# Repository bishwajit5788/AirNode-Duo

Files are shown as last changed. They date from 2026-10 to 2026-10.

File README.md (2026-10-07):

# AirNode Duo

> **ESP32-C3 controlled dual-BLDC personal airflow and thermoelectric cooling system**

**Motto:** *Cool the person, not the room — compact airflow where it matters.*

Repository: [github.com/bishwajit5788/AirNode-Duo](https://github.com/bishwajit5788/AirNode-Duo)

---

## 1. Purpose

AirNode Duo is a compact personal airflow system meant to mount above a person inside:

- a mosquito net  
- a single-bed sleeping area  
- a lightweight camping tent  
- a compact temporary sleeping space  

Two BLDC motors with propellers produce **downward airflow** similar to a ceiling fan. The goal is **perceived cooling through forced convection** — moving useful air toward the person — not refrigerating a room.

**This system is not:**

- a room air conditioner  
- a refrigerator for the sleeping space  
- a device that produces ice-cold air  

Motor 1 may use an experimental thermoelectric liquid loop to slightly cool the air it moves. Motor 2 remains a normal, unobstructed airflow motor.

---

## 2. Physical architecture

```text
                  MOSQUITO NET / TENT ROOF
        ===========================================

              MOTOR 1             MOTOR 2
           2312 920KV CW       2312 920KV CW
                │                   │
              PROP 1              PROP 2
                ↓                   ↓
             cooled              normal
             airflow             airflow
                ↓                   ↓
              ↓↓↓↓↓             ↓↓↓↓↓
                 \               /
                  \             /
                   \           /
                    PERSON
```

- Two motors on a **lightweight, symmetric, roof-mounted frame**
- Heavy AC–DC PSU stays **outside** the hanging assembly
- Only low-voltage DC wiring runs up to the roof unit

---

## 3. Motors

| Item | Value |
|---|---|
| Part | Readytosky **2312 920KV CW** BLDC |
| Quantity | 2 |
| KV | ~920 RPM/V |
| Mass | ~48 g each |
| Diameter / body | ~27.7 mm OD × ~26 mm |
| No-load current | ~0.45 A at 10 V |
| Max continuous current | ~14 A (nameplate) |
| Max continuous power | ~220 W (nameplate) |
| Voltage class | ~2S–4S equivalent |
| Selected propeller | **9450 carbon fiber CW** (primary) |
| Other prop families considered | 9443, 9450, 1045 |

**Do not assume** “30 A ESC ⇒ 30 A motor current.” Actual current depends on propeller, voltage, throttle, blockage, and mounting. **Measure** current on the finished hardware.

---

## 4. Propellers

| Candidate | Role |
|---|---|
| **9450** | **Selected primary propeller** (carbon fiber, F450/F550 class) |
| 9443 | Lower-load baseline |
| 9350 | Smaller alternate |
| 1045 | Larger swept-area comparison |

**9450** is approximately **9.4″ diameter** (~**239 mm** tip-to-tip) with a **5.0″ pitch**.

Printed motor frames (motors **inside** the cages) are in [`hardware/frames/`](hardware/frames/):

- Motor 2 (air only): **253.47 × 253.47 × 61.0 mm** bottom + top grille  
- Motor 1 (copper coil under motor): **253.47 × 253.47 × 71.0 mm** bottom + top grille  

Always **measure** motor/ESC current and temperature with the installed 9450 + guards. Do not assume current from the ESC rating.

---

## 5. ESCs

| Item | Value |
|---|---|
| Part | Favorite **LittleBee 30A-S OPTO** × 2 |
| Class | 30 A, BLHeli_S, 2–6S |
| BEC | **None (OPTO)** |

- ESC #1 → Motor #1  
- ESC #2 → Motor #2  
- ESCs **do not** power the ESP32  
- ESP32 is powered by a separate **12 V → 5 V buck converter**

---

## 6. Main power supply

| Item | Value |
|---|---|
| PSU | 7SEVEN/MJF (or equivalent) |
| Rating | **12 V / 50 A / 600 W**, IP44 |

- PSU stays **outside** the hanging assembly  
- AC mains path: fuse → master switch → SMPS  

**Nameplate motor budget (upper bound, not measured load):**  
2 × 14 A = 28 A → 28 A × 12 V ≈ **336 W**.  
The 600 W PSU has headroom on paper; that is **not** validation of continuous 600 W system use. Other loads: Peltier, pump, hot-side fan, ESP32, losses. **Measure** real current and thermal behavior.

---

## 7. Electrical architecture

```text
                      230 V AC MAINS
                            │
                [Fuse + Master Switch]
                            │
                ┌───────────▼───────────┐
                │ 12 V / 50 A / 600 W   │
                │      AC-DC SMPS        │
                └───────────┬───────────┘
                            │
          ┌─────────┬───────┼───────┬─────────┐
          │         │       │       │         │
       ESC #1    ESC #2  Peltier  Pump   12→5 V buck
          │         │    driver   │         │
       Motor 1   Motor 2    TEC   │      ESP32-C3
          │         │             │      Wi-Fi AP
       PROP 1    PROP 2           │         │
                                  │       PHONE
                             (+ hot-side fan)
```

ESP32 GPIOs only drive **signal / driver** circuits. They must **not** power motors, ESCs, Peltier, or pump directly.

---

## 8. ESP32-C3 controller

**Board:** ESP32-C3 Mini (or compatible).

**Responsibilities:**

- Wi-Fi SoftAP + captive-portal helpers  
- Local web UI and HTTP API  
- Motor targets, ramp, START/STOP  
- Cooling sequence and interlocks  
- Heartbeat failsafe  
- Future sensor telemetry (not invented until sensors exist)

---

## 9. Wi-Fi user experience

1. Power on → ESP32 boots  
2. SoftAP appears: **AirNode-Duo**  
3. User joins the network  
4. Captive-portal detection *may* open the control page (OS-dependent)  
5. Always available: **http://192.168.4.1**  

**No internet required.** Core control is fully local.

| Setting | Value |
|---|---|
| SSID | `AirNode-Duo` |
| Password | `airnode123` |
| AP IP | `192.168.4.1` |
| Subnet | `255.255.255.0` |

Captive helpers include DNS wildcard → `192.168.4.1` and common paths such as `/generate_204`, `/hotspot-detect.html`, `/connecttest.txt`, `/ncsi.txt`, `/canonical.html`, `/success.txt`. **Do not claim** every phone OS will auto-open the page.

---

## 10. Phone control interface

Mobile-first local page:

- Title: **AirNode Duo**  
- Connection: ● CONNECTED / FAILSAFE / DISCONNECTED  
- IP: 192.168.4.1  
- System: ARMING / ARMED / RUNNING / STOPPED / FAILSAFE  
- Motor 1 & Motor 2: 2312 920KV CW, 0–100% sliders, target + applied %  
- Master speed: sets both targets (then adjustable independently)  
- **START** / **STOP** (STOP always prominent)  
- Thermoelectric cooling: ON/OFF, pump and TEC status  

---

## 11. Motor control behavior

| Phase | Behavior |
|---|---|
| Boot | Both ESC outputs **1000 µs**; motors stay off |
| Arm | Wait **3 s** before START is accepted |
| START | Explicit user action only; controlled **ramp** toward targets |
| STOP | Motors → off; cooling forced off |
| Failsafe | No valid control/heartbeat for **1.5 s** while running → motors + cooling off |

Browser sends heartbeats ~**500 ms**. After failsafe or reconnect, motors **do not** auto-restart; user must press **START** again.

Firmware ramps targets; it does **not** jump instantly from 0% to a high throttle on START.

---

## 12. Thermoelectric cooling (Motor 1)

**Concept:** Peltier cools **coolant**, not air directly. Coolant cools a copper coil; Motor 1 airflow passes over the coil.

```text
12 V Peltier → cold-side block → coolant → pump → tubing
    → copper coil (behind Motor 1 prop) → airflow → person
```

| Item | Notes |
|---|---|
| Peltier | ~12 V / ~2 A class (~20 W ideal); **not** room AC |
| Hot side | Aluminium heatsink + dedicated fan; heat must leave the cold path |
| Coil | Must **not** fully block the prop disc (load, current, heat rise) |
| Tube size | If “1 mm” is **internal** diameter, flow resistance may be excessive — verify ID vs wall |

### Cooling sequence (firmware)

1. COOLING ON  
2. Motor 1 running and applied ≥ ~**20%**  
3. Pump ON  
4. Wait ~**2 s** (prime)  
5. TEC driver ON → **ACTIVE**  

If Motor 1 stops / drops below threshold, or STOP/failsafe: **TEC off**, **pump off**.

### Cooling safety gaps (not yet instrumented)

Firmware does **not** yet verify coolant flow, hot-side temperature, cold-side temperature, or condensation. Future work: sensors, flow/pump-fail detection, condensation management. Avoid uncontrolled leakage above person, ESP32, ESCs, or power joints (sealed reservoir, secure fittings).

---

## 13. GPIO map (firmware defaults)

Centralized in `firmware/src/config.h` — do not scatter pin numbers.

| Function | GPIO | Notes |
|---|-----:|---|
| ESC #1 signal | 4 | Logic-level PWM only |
| ESC #2 signal | 5 | Logic-level PWM only |
| Pump driver | 6 | MOSFET/driver stage only |
| TEC driver | 7 | MOSFET/driver stage only |

Verify against the **exact** board pinout before connecting loads.

---

## 14. Firmware layout

```text
firmware/
├── platformio.ini
├── README.md          ← build, flash, API, bench checklist
└── src/
    ├── main.cpp
    ├── config.h
    ├── wifi_manager.*
    ├── web_server.*
    ├── motor_control.*
    ├── cooling_control.*
    └── web_ui.*
```

Responsibilities stay separated: Wi-Fi, web, motors, cooling, configuration, UI.

### HTTP API (local only)

| Method | Path | Role |
|---|---|---|
| GET | `/` | Control page |
| GET | `/api/status` | JSON state |
| POST | `/api/start` | Start (after arm) |
| POST | `/api/stop` | Hard stop |
| POST | `/api/control` | `m1`, `m2` ∈ 0…100 |
| POST | `/api/master` | `speed` ∈ 0…100 |
| POST | `/api/heartbeat` | Keep-alive |
| POST | `/api/cooling` | `on=0` or `on=1` |

All inputs validated and clamped. No fake temperature/current fields in JSON.

Example status:

```json
{
  "armed": true,
  "running": true,
  "failsafe": false,
  "motor1_target": 45,
  "motor1_applied": 42,
  "motor2_target": 45,
  "motor2_applied": 42,
  "cooling_requested": true,
  "pump": true,
  "tec": true,
  "clients": 1,
  "ip": "192.168.4.1"
}
```

Details: **[firmware/README.md](firmware/README.md)**.

---

## 15. Safety requirements

Rotating machinery above a person makes safety a **core** requirement.

**Mechanical:** full prop guards, rigid mounts, vibration-resistant fasteners, balanced frame, secondary tether, keep net fabric / hair / fingers out of the disc.

**Electrical:** AC fuse, master switch, proper mains enclosure/earthing as applicable, correct wire gauge, strain relief, secure connectors; AC section stays off the hanging assembly.

**Software:** motors off at boot; controlled ramp; heartbeat failsafe; no auto-restart after disconnect; cooling interlocks; reject invalid API input.

**Physical emergency disconnect** is strongly recommended. Software STOP is **not** the only emergency path.

---

## 16. Testing procedure

### Stage A — no propellers

**Remove both propellers** before any ESC test.

1. ESP32 boot, AP, phone join, `http://192.168.4.1`  
2. Captive-portal behavior where the OS supports it  
3. ESC arming (3 s), START at 0%, Motor 1 / Motor 2 independently  
4. STOP, Wi-Fi drop → failsafe within ~1.5 s, no auto-restart  
5. Cooling: pump before TEC; TEC off when Motor 1 low/stopped  

### Stage B — loaded (only after Stage A)

Propellers + guards; measure current, temperatures, vibration, noise, airflow; long-duration runs; cooling thermal and condensation checks.

**Firmware compile success ≠ hardware validation.**

---

## 17. Project status

**Stage:** Hardware architecture / **prototype development**

Repository includes concept docs, cooling diagrams, PlatformIO firmware (modular SoftAP UI, dual ESC, ramp, failsafe, cooling sequence), and CI build workflow.

| Claim type | Status |
|---|---|
| Firmware designed & modularized | Yes |
| Firmware compile verification | **Pending CI result after current PWM compatibility fix** |
| Physical motor/cooling validation | **Not complete** — pending bench & field tests |

Do **not** mark hardware validation complete without measurements.

---

## 18. Development roadmap

**Firmware (implemented in repo):**

- [x] ESP32-C3 Wi-Fi SoftAP (`AirNode-Duo` / `airnode123` → 192.168.4.1)  
- [x] Local web UI + captive-portal DNS/redirects  
- [x] Dual ESC PWM, independent + master speed  
- [x] Controlled startup ramp, explicit START/STOP  
- [x] Heartbeat failsafe (1.5 s; no auto-restart)  
- [x] Cooling sequence (pump prime → TEC; Motor 1 airflow interlock)  
- [x] Modular `src/` layout
- [x] Arduino-ESP32 3.x-compatible LEDC ESC output (14-bit at 50 Hz)
- [x] Arduino-ESP32 2.x compatibility path retained  

**Next / hardware:**

- [ ] Captive-portal polish on more phone OS versions  
- [ ] Current / voltage sensing  
- [ ] Motor, ESC, TEC hot-side, coolant temperature  
- [ ] Coolant flow / pump-fail detection  
- [ ] Live telemetry (only with real sensors)  
- [ ] Stronger cooling safety state machine  
- [ ] Physical emergency-stop input  
- [ ] Prop guards, frame, long-duration thermal/vibration tests  
- [x] Propeller selected: **9450 carbon fiber CW** (current/temp validation still required)  

---

## 19. Engineering rules (summary)

- Do not invent measurements or claim untested hardware capability  
- Do not treat 600 W PSU rating as actual system consumption  
- Do not equate PWM % with motor current  
- Do not claim the Peltier air-conditions the tent  
- Do not drive high-current loads from ESP32 GPIO  
- Do not auto-start motors after boot or after failsafe/reconnect  
- Do not enable TEC without pump-prime + airflow logic  
- Core control must work **without** internet or cloud  

---

## 20. Verification status

The repository is ready for the next software/bench-test stage, but physical operation is still unverified.

### Resolved in the current firmware

- Updated ESC PWM handling for Arduino-ESP32 3.x (ledcAttach / pin-based ledcWrite).
- Retained a compatibility path for Arduino-ESP32 2.x.
- Changed ESP32-C3 ESC PWM resolution from 16-bit to **14-bit**, matching the current Arduino-ESP32 LEDC range for ESP32-C3.
- Added a PWM-initialization failure lockout so the controller cannot arm motors if LEDC setup fails.

### Still requires physical hardware validation

- Exact ESP32-C3 board pinout.
- ESC signal/arming behavior with the selected LittleBee ESCs.
- Motor/propeller current and temperature.
- Propeller direction and downward airflow.
- Frame strength, vibration and guards.
- Peltier hot-side temperature.
- Coolant flow and leak resistance.
- Condensation behavior.
- Physical emergency disconnect.

**A successful firmware build does not prove that the motor/cooling system is safe for operation above a person.**

## 20. Documentation map

| Path | Role |
|---|---|
| **[README.md](README.md)** (this file) | Full project context, architecture, safety, roadmap |
| **[firmware/README.md](firmware/README.md)** | Build, flash, API, GPIO, bench checklist |
| [docs/project-concept.md](docs/project-concept.md) | Concept notes |
| [hardware/README.md](hardware/README.md) | Hardware notes |
| [docs/](docs/) / [hardware/](hardware/) | Diagrams and prototype media |

---

## 22. Intended end-to-end experience

```text
USER POWERS AIRNODE DUO
        │
        ▼
ESP32-C3 BOOTS  →  motors OFF, TEC OFF, pump OFF
        │
        ▼
Wi-Fi AP "AirNode-Duo"
        │
        ▼
PHONE CONNECTS  →  captive portal and/or http://192.168.4.1
        │
        ▼
CONTROL PAGE  →  motor + cooling UI
        │
        ├── START + sliders  →  ramped dual airflow
        └── COOLING ON       →  pump → TEC (if Motor 1 OK)
        │
        ▼
DOWNWARD AIRFLOW  →  PERSON

If phone lost → 1.5 s timeout → FAILSAFE (motors + cooling OFF)
                → wait for user START again
```

---

## License

Choose and declare a license that matches the firmware, CAD, and documentation you intend to publish.

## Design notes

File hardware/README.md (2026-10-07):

# AirNode Duo — Hardware

This directory is the central hardware documentation area for the AirNode Duo prototype.

## Purpose

AirNode Duo is a lightweight, roof-mounted, Wi-Fi-controlled dual-BLDC airflow system for a mosquito net / compact sleeping space.

The current prototype concept combines:

- **Motor 1:** 2312 920KV CW BLDC + 9450-class CW propeller (carbon fiber)
- **Motor 2:** 2312 920KV CW BLDC + 9450-class CW propeller (carbon fiber)
- **Motor 1 cooling stage:** 12 V / ~2 A Peltier + liquid coolant loop + copper tube coil behind the propeller
- **Motor 2:** normal unobstructed airflow
- **ESCs:** 2 × Favorite LittleBee 30A-S OPTO
- **Controller:** ESP32-C3
- **Main supply:** external 12 V / 50 A / 600 W AC-DC SMPS
- **Logic supply:** 12 V → 5 V buck converter
- **Cooling loop:** Peltier cold block → pump → flexible tube → copper coil → return
- **Hot side:** aluminium heatsink + dedicated cooling fan

## Hardware layout

The intended arrangement is:

```text
                         MOSQUITO-NET ROOF
────────────────────────────────────────────────────────

        MOTOR 1                                  MOTOR 2
      2312 920KV                               2312 920KV
           │                                        │
         9450                                     9450
           │                                        │
           ▼                                        ▼
   ┌───────────────┐                         NORMAL AIRFLOW
   │ COPPER COIL   │                               ↓↓↓
   │ HEAT EXCHANGER│                               ↓↓↓
   └───────┬───────┘                               ↓↓↓
           ↓
      COOLED AIRFLOW
           ↓
        OCCUPANT

        PELTIER
           │
      COLD-SIDE BLOCK
           │
        COOLANT
           │
          PUMP
           │
     PLASTIC TUBE
           │
     COPPER COIL
           │
         RETURN

    HOT SIDE → ALUMINIUM HEATSINK + FAN → HOT AIR AWAY
```

## Hardware specification

| Subsystem | Component | Specification / role |
|---|---|---|
| Airflow | 2 × BLDC motor | Readytosky 2312 920KV |
| Propeller | 2 × | 9450 carbon fiber CW; current/temp to be measured with guards |
| Motor ESC | 2 × | Favorite LittleBee 30A-S OPTO |
| Controller | 1 × | ESP32-C3, Wi-Fi web control |
| Main PSU | 1 × | 12 V / 50 A / 600 W external SMPS |
| Logic PSU | 1 × | 12 V → 5 V buck converter |
| TEC | 1 × | 12 V / ~2 A Peltier class |
| Cold-side exchanger | 1 × | Copper/aluminium water block |
| Liquid pump | 1 × | Small 12 V pump |
| Air heat exchanger | 1 × | Copper tube coil behind Motor 1 propeller |
| Tubing | As required | Flexible coolant tubing; size to be selected from pump/flow testing |
| Hot-side cooling | 1 × | Aluminium heatsink + 12 V cooling fan |
| Reservoir | 1 × | Sealed coolant reservoir |
| Sensors | Recommended | Hot-side, cold-side/coolant temperature; optional flow sensor |
| Safety | Required | Prop guards, fuse/protection, master disconnect, secondary safety tether |

## Photo archive

This folder is intentionally structured as a **living hardware archive**.

Add future prototype photographs here using descriptive filenames:

```text
hardware/
├── README.md
├── concept/
│   └── airnode-duo-minimal-diagram.jpg
├── prototype/
│   ├── 2026-XX-XX_frame.jpg
│   ├── 2026-XX-XX_motor-1.jpg
│   ├── 2026-XX-XX_motor-2.jpg
│   ├── 2026-XX-XX_peltier-loop.jpg
│   ├── 2026-XX-XX_copper-coil.jpg
│   ├── 2026-XX-XX_control-electronics.jpg
│   └── 2026-XX-XX_complete-prototype.jpg
└── testing/
    ├── airflow-test/
    ├── thermal-test/
    └── electrical-test/
```

### Photo naming convention

Use:

```text
YYYY-MM-DD_component_or_view_description.jpg
```

Examples:

- `2026-10-05_complete-prototype.jpg`
- `2026-10-05_motor-1-copper-coil.jpg`
- `2026-10-05_peltier-cold-block.jpg`
- `2026-10-05_hot-side-heatsink.jpg`
- `2026-10-05_esp32-esc-wiring.jpg`

For every real hardware photograph, add a short caption containing:

1. What is shown
2. Component/model
3. Purpose
4. Relevant specification
5. Prototype revision/date
6. Any important modification

## Important prototype notes

- The copper coil is a **liquid-to-air heat exchanger** positioned behind Motor 1's propeller.
- The Peltier must be thermally coupled to a proper cold-side block; do not rely on direct contact with the tube.
- The hot side must continuously reject heat through an adequately sized heatsink and fan.
- The coil must not excessively obstruct the propeller.
- If the proposed 1 mm copper tube means **1 mm internal diameter**, re-evaluate it because the pressure drop may be excessive for a small pump.
- Use a sealed reservoir and leak-resistant fittings because the assembly is positioned above the occupant.
- Condensation must be checked before continuous operation.
- Actual motor current must be measured with the final propeller before selecting operating limits.
- Software control is not the only safety mechanism: use physical electrical and mechanical protection.

## Current status

**Stage:** Concept / hardware preparation

**Next hardware milestone:** assemble and photograph the first physical frame, cooling loop and electrical/control assembly. Replace concept illustrations with real prototype photographs as the hardware becomes available.

## Current concept image

The current project concept image is stored directly in the hardware archive:

AirNode Duo hardware concept

This image represents the **current design concept**, not a photograph of the assembled physical prototype. Future real hardware photographs should be added under `hardware/prototype/` with dated filenames and captions.

## Concept diagrams

- [Thermoelectric cooling (SVG)](concept/airnode-duo-thermoelectric-cooling.svg) — schematic diagram
- [Thermoelectric cooling (PNG)](concept/airnode-duo-thermoelectric-cooling.png) — generated concept illustration
- [Thermoelectric cooling (JPG)](concept/airnode-duo-thermoelectric-cooling.jpg) — same illustration

## Propeller guards / motor frames (3D printed)

Printed parts live in **[`frames/`](frames/)** with a full parts list and print notes.

| Node | Bottom cage | Height Z | Notes |
|---|---|---|---|
| Motor 1 (cooled) | `frames/b-frame-71mm-cooled.stl` | **71.0 mm** | Extra height for copper coil under motor |
| Motor 2 (air only) | `frames/b-frame-61mm.stl` | **61.0 mm** | No liquid coil |
| Both | `frames/t-frame.stl`, `t-frame-2.stl` | **4.54 mm** | Top grilles (one per node) |

Outer footprint: **253.47 × 253.47 mm**. Motors mount **inside** the cages. Propeller: **9450** carbon (~239 mm disc).

See [`frames/README.md`](frames/README.md) for assembly, print settings, and fit notes.

## Center control / cooling enclosure

Low-profile box for ESP32-C3, **TEC1-12706**, 40×40 water block, heatsink+fan, and **RF-370CA-12560** pump.

| Part | File | Size (mm) |
|---|---|---|
| Body | [`enclosure/case-body.stl`](enclosure/case-body.stl) | **130 × 110 × 50** |
| Lid | [`enclosure/cap.stl`](enclosure/cap.stl) | **130 × 110 × 15** |

**Print-ready** open-top shell. Designed for **flat** TEC stack and **side** hot-air exhaust so height stays low on a mosquito net / tent.

Full notes: [`enclosure/README.md`](enclosure/README.md)

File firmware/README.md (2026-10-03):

# AirNode Duo — Firmware

PlatformIO firmware for the ESP32-C3 SoftAP controller.

For full project architecture, safety, and hardware context, see the **[root README](../README.md)**.

---

## Quick start

```bash
cd firmware
pio run                 # build
pio run -t upload       # flash
pio device monitor      # 115200 baud
```

---

## Wi-Fi

| Setting | Value |
|---|---|
| SSID | `AirNode-Duo` |
| Password | `airnode123` |
| Control URL | **http://192.168.4.1** |

No internet required. Captive-portal DNS/redirects are implemented; phone OS behavior varies — use the URL if the page does not open automatically.

---

## GPIO defaults (`src/config.h`)

| Function | GPIO |
|---|-----:|
| ESC #1 | 4 |
| ESC #2 | 5 |
| Pump driver | 6 |
| TEC driver | 7 |

Verify against your board. Drivers only — never load GPIO directly with pump/Peltier/motor power.

---

## PWM compatibility

The ESC outputs use **50 Hz servo-style PWM** with **14-bit LEDC resolution** on ESP32-C3.

The implementation supports the current Arduino-ESP32 3.x LEDC API (`ledcAttach` / pin-based `ledcWrite`) and retains a compatibility path for Arduino-ESP32 2.x.

If LEDC initialization fails, the firmware locks the motor outputs off and does not arm the controller.

## API

| Method | Path | Body / notes |
|---|---|---|
| GET | `/` | Control UI |
| GET | `/api/status` | JSON |
| POST | `/api/start` | After 3 s arm |
| POST | `/api/stop` | Motors + cooling off |
| POST | `/api/control` | `m1=0..100&m2=0..100` |
| POST | `/api/master` | `speed=0..100` |
| POST | `/api/heartbeat` | ~500 ms from browser |
| POST | `/api/cooling` | `cooling=0..100` or `on=0|1` (also JSON) |

Failsafe: no valid control for **1.5 s** while running → stop motors and cooling; no auto-restart.

---

## Source layout

```text
src/
  main.cpp
  config.h
  wifi_manager.*
  web_server.*
  motor_control.*
  cooling_control.*
  web_ui.*
```

---

## Bench test (propellers **removed**)

1. Power ESP32 from 12 V → 5 V buck; ESCs from 12 V per manufacturer wiring.  
2. Flash, join **AirNode-Duo**, open **http://192.168.4.1**.  
3. Wait until UI shows **ARMED**.  
4. START at 0%; raise Motor 1 then Motor 2 slowly.  
5. Drop Wi-Fi / close page → failsafe within ~1.5 s.  
6. Reconnect → motors stay off until **START**.  
7. Cooling: Motor 1 ≥ 20% → COOLING ON → pump then TEC after ~2 s.  

Software failsafe is not a substitute for a physical emergency disconnect.

**Build status:** use the GitHub Actions workflow as the authoritative compile check; this document does not claim a successful build until CI reports one.

Only after this passes should propellers and loaded tests begin (see root README).

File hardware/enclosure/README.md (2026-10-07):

# AirNode Duo — Center control / cooling enclosure

Low-profile 3D-printed box for the **balanced center node** on the mosquito-net / tent structure.

## Files (print-ready)

| File | Role | Bounding box (mm) | Mesh notes |
|---|---|---|---|
| `case-body.stl` | Main body | **130 × 110 × 50** | **Open top** for lid; cleaned for FDM |
| `cap.stl` | Lid | **130 × 110 × 15** | Watertight; print flat |

## 3D print settings (recommended)

| Setting | Body | Lid |
|---|---|-----|
| Material | **PETG** | PETG |
| Nozzle | 0.4 mm | 0.4 mm |
| Layer height | **0.20 mm** | 0.20 mm |
| Walls / perimeters | **3** | 3 |
| Top/bottom layers | 4–5 | 4–5 |
| Infill | **15–25%** gyroid or grid | 15–25% |
| Supports | **None** (correct orientation) | None |
| Orientation | **Open face UP**, floor on bed | Flat on bed |

### Orientation

```text
case-body.stl                 cap.stl
   open top ↑
   ┌─────────┐               ┌─────────┐
   │  cavity │               │   lid   │
   │  floor  │ ← on bed      └─────────┘ ← on bed
   └─────────┘
```

### Printability

- Body is an **open-top shell** (not a sealed hollow bubble) so FDM slices cleanly.
- Floor at Z = 0 for bed contact.
- After print: drill **Ø8–9 mm** side holes for RF-370 / block tubing if needed.
- Cut or design a **side grille** for TEC heatsink fan exhaust (hot air out, not into the net).

### Fit

| Item | Guidance |
|---|---|
| Internal height | ~47–48 mm above floor |
| Pump RF-370 | ~84 mm × Ø29 — along 130 mm axis |
| TEC stack | **Flat**; fan exhaust **sideways** |
| Lid | Light friction or M3 corner screws |

## Contents

| Component | Spec |
|---|---|
| ESP32-C3 + buck 12→5 V | Dry side |
| TEC1-12706 | 40×40×~3.8 mm; MOSFET only (~4–6 A) |
| Water block | 40×40×(12+7) mm |
| Heatsink + fan | Compact TEC kit |
| Pump | RF-370CA-12560, Ø8 mm ports |

## Safety

- TEC/pump via MOSFET — never direct ESP32 GPIO.
- Leak-test before enabling TEC.
- Secondary tether on hanging assembly.

## Related

- Motor frames: [`../frames/`](../frames/)
- Hardware overview: [`../README.md`](../README.md)

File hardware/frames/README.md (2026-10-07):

# AirNode Duo — 3D-printed motor frames

Printed propeller guards / motor cages for the dual-node AirNode Duo prototype.

Motors mount **inside** the frames. Each node is a **bottom cage + top grille**.

## Files

| File | Role | Bounding box (mm) | Triangles |
|---|---|---|---|
| `b-frame-61mm.stl` | **Motor 2** bottom cage (air-only, no liquid coil) | **253.47 × 253.47 × 61.0** | 240 288 |
| `b-frame-71mm-cooled.stl` | **Motor 1** bottom cage (space for copper cooling coil under motor) | **253.47 × 253.47 × 71.0** | 240 288 |
| `t-frame.stl` | Top grille (pair with either bottom) | **253.47 × 253.47 × 4.54** | 102 108 |
| `t-frame-2.stl` | Second top grille (print one per node) | **253.47 × 253.47 × 4.54** | 102 108 |

## Which frame for which motor

```text
Motor 1 (cooled path)          Motor 2 (normal airflow)
┌─────────────────────┐        ┌─────────────────────┐
│ t-frame*.stl        │        │ t-frame*.stl        │
│ 9450 prop           │        │ 9450 prop           │
│ 2312 motor          │        │ 2312 motor          │
│ copper coil ~20 mm  │        │ (no coil)           │
│ b-frame-71mm-cooled │        │ b-frame-61mm        │
└─────────────────────┘        └─────────────────────┘
     Z = 71 mm                      Z = 61 mm
     X = Y ≈ 253.5 mm               X = Y ≈ 253.5 mm
```

| Node | Bottom STL | Top STL | Z height |
|---|---|---|---|
| **Motor 1** (Peltier liquid coil under motor) | `b-frame-71mm-cooled.stl` | `t-frame.stl` or `t-frame-2.stl` | **71.0 mm** |
| **Motor 2** (no coil) | `b-frame-61mm.stl` | `t-frame.stl` or `t-frame-2.stl` | **61.0 mm** |

Height difference (**+10 mm** on Motor 1) is for the self-made thin copper cooling coil (~15–20 mm pack) under the motor inside the cage.

## Propeller compatibility

| Item | Value |
|---|---|
| Propeller | **9450** carbon fiber (F450/F550 class), CW |
| Prop disc | ~**9.4″ ≈ 239 mm** tip-to-tip |
| Frame outer | ~**253.5 mm** |
| Typical wall | ~3–4 mm → inner clear ~**245–247 mm** |
| Fit | **Usable** if prop is centered; measure real prop and inner Ø before high throttle |

## Motor compatibility

| Item | Value |
|---|---|
| Motor | Readytosky **2312 920KV** CW |
| Body height | **26.0 mm** (datasheet) |
| Body diameter | **27.7 mm** |
| Mount | **12 × 16 mm** M3 pattern — verify against base plate holes |

## Bill of printed parts (one complete dual-motor set)

- 1 × `b-frame-71mm-cooled.stl` (Motor 1)
- 1 × `b-frame-61mm.stl` (Motor 2)
- 2 × top grille (`t-frame.stl` + `t-frame-2.stl`)

## Suggested print settings (Bambu Lab A1 reference)

| Setting | Suggestion |
|---|---|
| Material | **PETG** (toughness for guards) |
| Nozzle | 0.4 mm |
| Layer height | 0.20 mm |
| Walls | 3 loops |
| Infill | 15–25% (tri-hexagon or gyroid) |
| Supports | As needed for the side windows / overhangs |
| Orientation | Base flat on bed (Z up) |

Always dry-fit **motor + prop (and coil on Motor 1)** before final assembly.

## Assembly notes

1. Mount the **2312** to the center of the **bottom** cage (motor inside).
2. Install **9450** on the motor shaft (correct CW direction for downward airflow).
3. On Motor 1 only: place the **copper coil** under the motor / in the extra Z space; route inlet/outlet through a side opening — do not fully block the prop disc.
4. Fit the **top grille**; ensure prop tips clear the inner wall and grille.
5. Route ESC/signal wires out a side window with strain relief.
6. Use a **secondary safety tether** on the hanging assembly.

## Safety

- First electrical tests: **propellers removed**.
- First spinning tests: low throttle, guards on, no body over the disc.
- These frames are **guards**, not a substitute for careful mounting and current measurement.

## Source

Derived from a freely available fan-cover / 风扇罩 style model, scaled in Z per node:

- Motor 2 air-only: **Z = 61 mm**
- Motor 1 cooled: **Z = 71 mm**
- X/Y held at model outer ~**253.5 mm**

Original concept dimensions and AirNode Duo system docs: see [`../README.md`](../README.md) and the repository root `README.md`.

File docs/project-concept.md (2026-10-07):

# AirNode Duo — Project Concept

## Motto

> **Cool the person, not the room — compact airflow where it matters.**

## Physical arrangement

AirNode Duo uses two roof-mounted BLDC rotors positioned over the sleeping area. Both rotors are intended to produce **downward airflow**, creating a ceiling-fan-like circulation pattern.

The heavy AC-to-DC SMPS remains on the floor/table or another protected location. The roof assembly carries only the lightweight motors, ESCs, ESP32-C3, buck converter, wiring and safety hardware.

```text
                 ROOF OF MOSQUITO NET / TENT
        ──────────────────────────────────────────

              ┌───────────┐     ┌───────────┐
              │ 2312 920KV│     │ 2312 920KV│
              │  BLDC #1  │     │  BLDC #2  │
              └─────┬─────┘     └─────┬─────┘
                    │                   │
                ┌───▼───┐           ┌───▼───┐
                │  PROP  │           │  PROP  │
                └───┬───┘           └───┬───┘
                    ↓↓↓                 ↓↓↓
                 ↓↓↓↓↓↓↓             ↓↓↓↓↓↓↓
                    ↓↓↓                 ↓↓↓
                                      /
                                     /
                                    /
                          ▼▼▼▼▼▼▼▼▼
                         PERSON / BED

        ══════════════════════════════════════════
               12 V DC CABLE FROM OUTSIDE
                          │
                   ┌──────▼──────┐
                   │ 12V/50A/600W│
                   │     SMPS    │
                   └─────────────┘
                         230 V AC
```

## Motor 1 thermoelectric cooling module

The current concept adds a **12 V / ~2 A Peltier cooling stage to Motor 1**.

The Peltier does not sit directly in the propeller airflow. Instead:

1. The Peltier cold side cools a liquid through a proper cold-side thermal block.
2. A small pump circulates the coolant through flexible plastic tubing.
3. The coolant passes through a **copper tube coil positioned behind Motor 1's propeller**.
4. Motor 1 forces air across the copper coil.
5. The resulting cooled airflow continues downward toward the occupant.
6. The Peltier hot side is cooled separately with an aluminium heatsink and fan, with hot air directed away from the occupant.

```text
             MOTOR 1
          2312 920KV
               │
             9350
               ↓↓↓
        ┌───────────────┐
        │ COPPER COIL   │  ← coolant from pump
        └───────┬───────┘
                ↓↓↓
          COOLED AIRFLOW
                ↓↓↓
             PERSON

     PELTIER → COLD BLOCK → PUMP → COIL
        │
        └→ HOT SIDE → ALUMINIUM HEATSINK + FAN → HOT AIR OUT
```

The copper coil is therefore a **liquid-to-air heat exchanger**. It should not cover the entire propeller disc because excessive airflow blockage can reduce airflow and increase motor load.

A proper cold-side plate/water block and thermal interface material are required between the Peltier and coolant. If the proposed "1 mm copper tube" refers to internal diameter, a larger coolant passage should be considered because a very small passage can create excessive pressure drop.

Because the cold coil may reach temperatures below ambient dew point, condensation must be considered. A sealed coolant reservoir, leak-resistant fittings and temperature monitoring are recommended before mounting the system above a person.

## Design intent

The purpose is not to cool the whole room. The system creates a controlled local airflow stream across the occupant, which can improve perceived thermal comfort through increased convective heat transfer and evaporation.

The final system should prioritize:
- low mass on the net/tent roof;
- balanced and vibration-resistant mounting;
- controlled continuous airflow;
- independent rotor control;
- reliable shutdown on communication loss;
- physical rotor and electrical protection.

## Important design note

The two motors are both CW variants. Rotor direction and propeller installation must be verified experimentally so **both rotors produce the intended downward airflow**. Motor label convention alone does not establish airflow direction.

The hardware documentation is now maintained in `hardware/README.md`, with `hardware/concept/` reserved for clean concept diagrams and `hardware/prototype/` reserved for dated real-hardware photographs. Future prototype photos should document the frame, motors, propellers, copper coil, Peltier assembly, pump, wiring, controller and complete system.

## Current integrated hardware concept

The project has now evolved from a dual-airflow prototype into a **dual-airflow + Motor 1 thermoelectric cooling prototype**.

### Motor 1 — cooled airflow

**2312 920KV CW motor → 9350-class propeller → copper coolant coil → cooled downward airflow → occupant.**

The copper coil is a liquid-to-air heat exchanger. Coolant is circulated by a small pump through flexible tubing. The Peltier cools the coolant through a proper cold-side copper/aluminium block.

### Motor 2 — normal airflow

**2312 920KV CW motor → 9350-class propeller → unobstructed downward airflow → occupant.**

This provides independent airflow even when the thermoelectric stage is disabled.

### Thermal rejection

The Peltier hot side uses a dedicated aluminium heatsink and cooling fan. Hot air must be exhausted away from the occupant and away from the cooled coil. The Peltier's electrical input becomes additional heat that the hot side must reject, so heatsink capacity is a critical part of the design.

### Safety and validation priorities

- Use full propeller guards and a secondary safety tether.
- Keep the 230 V AC SMPS outside the hanging assembly.
- Use a sealed coolant reservoir and leak-resistant fittings.
- Add hot-side and cold-side/coolant temperature monitoring.
- Disable the Peltier if the hot side becomes too hot or coolant flow fails.
- Check for condensation before operation above a person.
- Do not allow the copper coil to excessively obstruct the propeller.
- Measure actual motor current with the final propeller before defining continuous operating limits.

### Hardware documentation structure

The repository now uses `hardware/README.md` as the central hardware file. It is intended to grow with the project and will contain future dated photographs and test documentation as the physical hardware arrives.

Current concept illustration:
`hardware/concept/airnode-duo-thermoelectric-cooling.svg`

Future real photographs:
`hardware/prototype/YYYY-MM-DD_description.jpg`

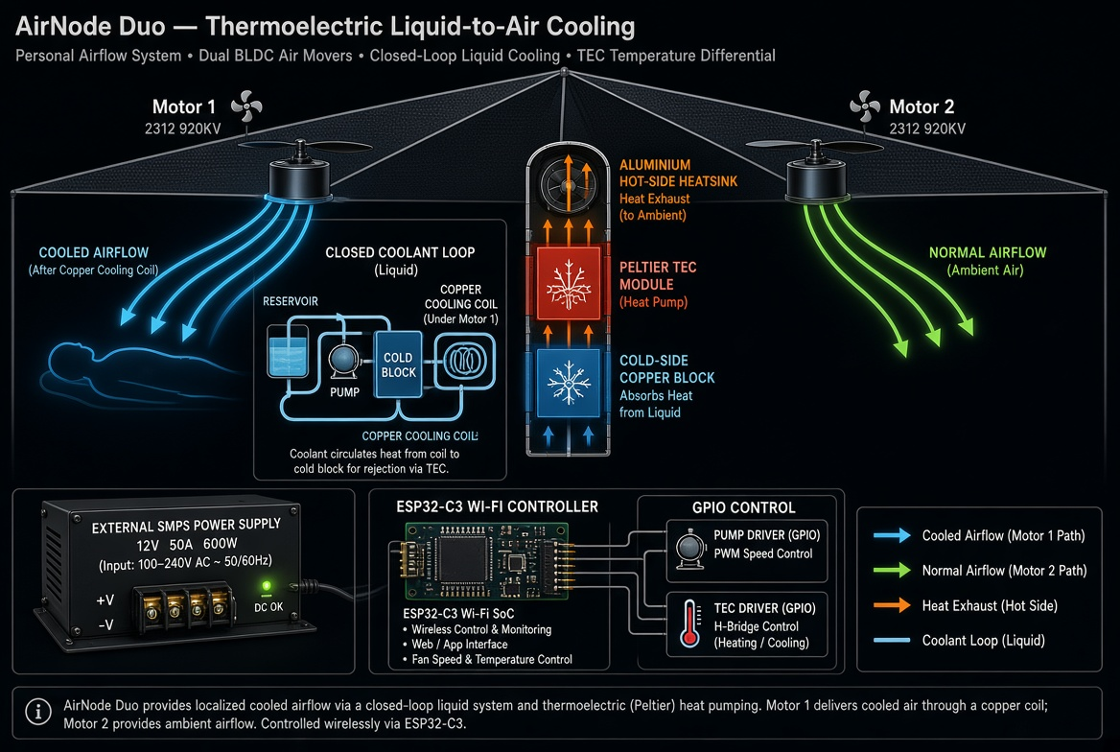
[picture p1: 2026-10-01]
hardware/concept/airnode-duo-thermoelectric-cooling.png

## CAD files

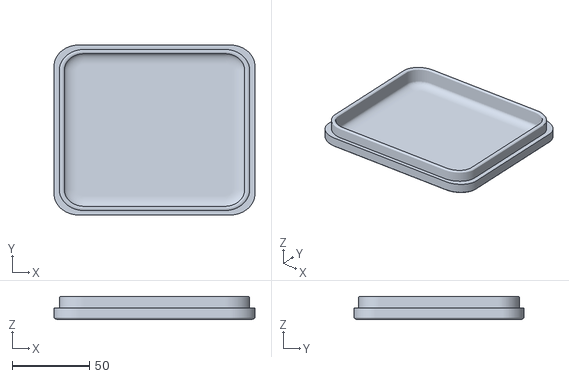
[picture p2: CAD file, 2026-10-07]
hardware/enclosure/cap.stl
130.0 x 110.0 x 15.0

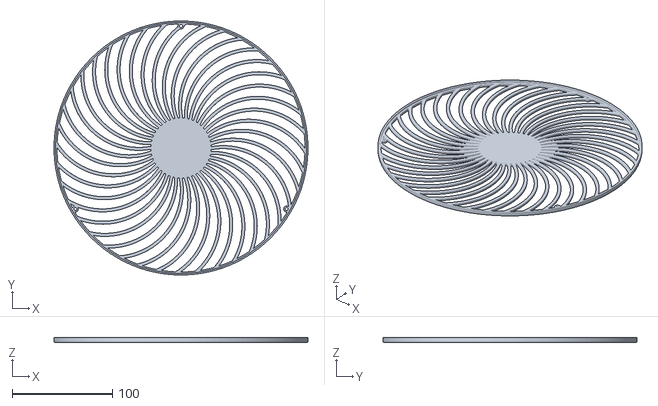
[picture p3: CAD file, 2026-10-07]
hardware/frames/t-frame.stl
253.5 x 253.5 x 4.54

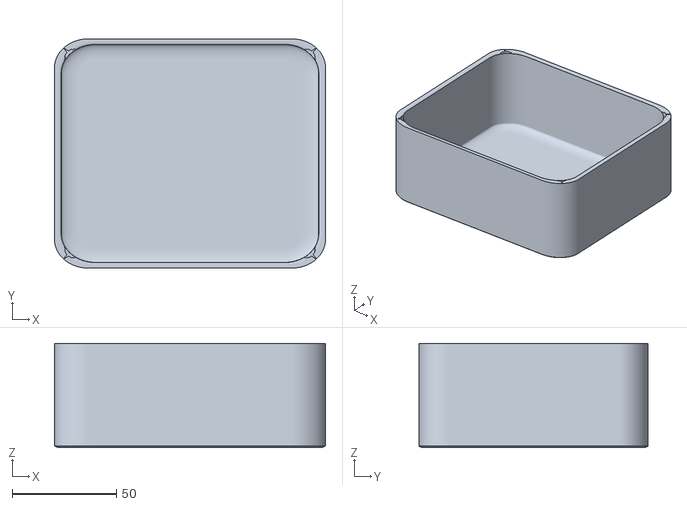
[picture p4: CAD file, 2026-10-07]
hardware/enclosure/case-body.stl
130.0 x 110.0 x 50.0

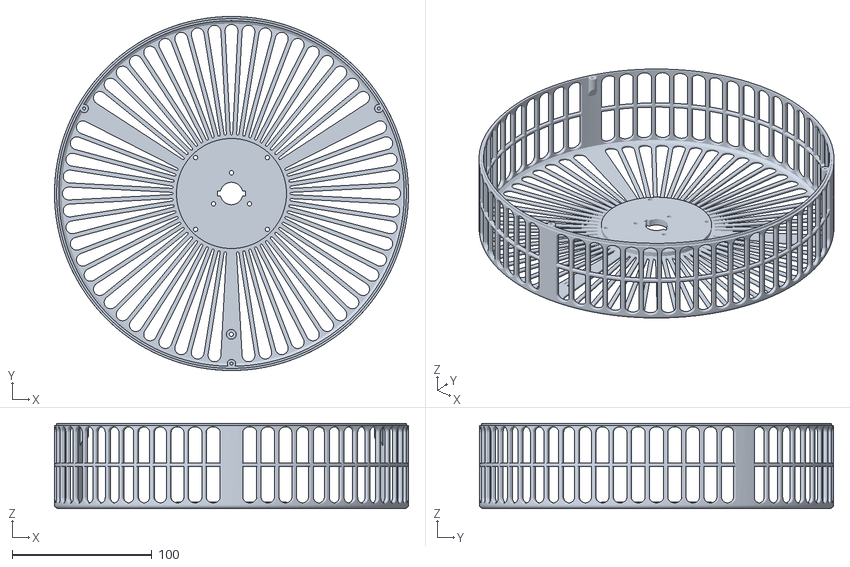
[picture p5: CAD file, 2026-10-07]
hardware/frames/b-frame-61mm.stl
253.5 x 253.5 x 61.0

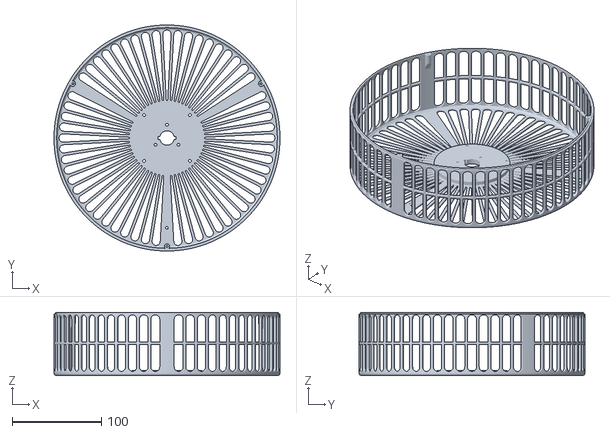
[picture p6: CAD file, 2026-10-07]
hardware/frames/b-frame-71mm-cooled.stl
253.5 x 253.5 x 71.0

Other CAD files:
hardware/frames/t-frame-2.stl

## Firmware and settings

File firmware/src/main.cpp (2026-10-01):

#include <Arduino.h>
#include "config.h"
#include "motor_control.h"
#include "cooling_control.h"
#include "wifi_manager.h"
#include "web_server.h"

void setup() {
  Serial.begin(115200);
  delay(50);

  Serial.println();
  Serial.println("AirNode Duo firmware booting...");

  MotorControl::begin();
  CoolingControl::begin();
  WifiManager::begin();
  WebServerApp::begin();

  Serial.println("Ready. Open http://192.168.4.1 after joining AirNode-Duo.");
}

void loop() {
  WifiManager::process();
  WebServerApp::process();

  MotorControl::update();

  // Cooling supervision uses live motor state
  CoolingControl::update(MotorControl::isRunning(), MotorControl::motor1Applied());

  // If failsafe just triggered motors, ensure cooling is off
  if (MotorControl::isFailsafe() && CoolingControl::isRequested()) {
    CoolingControl::forceOff();
  }

  delay(2);
}

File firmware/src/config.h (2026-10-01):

#pragma once

// AirNode Duo ESP32-C3 firmware configuration.
// Verify every GPIO against your exact ESP32-C3 board before connecting an ESC,
// pump driver, or TEC driver. Do not connect a load directly to an ESP32 GPIO.

// ---------------------------------------------------------------------------
// Wi-Fi SoftAP
// ---------------------------------------------------------------------------
#define AIRNODE_AP_SSID       "AirNode-Duo"
#define AIRNODE_AP_PASSWORD   "airnode123"
#define AIRNODE_AP_CHANNEL    6
#define AIRNODE_AP_MAX_CLIENTS 4

#define AIRNODE_IP_1 192
#define AIRNODE_IP_2 168
#define AIRNODE_IP_3 4
#define AIRNODE_IP_4 1

// ---------------------------------------------------------------------------
// GPIO map (centralized — do not hard-code pins elsewhere)
// ---------------------------------------------------------------------------
// ESC signal outputs. Logic-level PWM only (50 Hz servo-style).
// ESP32-C3 LEDC supports up to 14-bit resolution in Arduino-ESP32 3.x.
#define ESC1_PIN 4
#define ESC2_PIN 5

// Driver-control outputs. Must drive MOSFET/driver stages, never the load.
// Set to -1 when the hardware is not fitted.
#define PUMP_PIN 6
#define TEC_PIN  7

// ---------------------------------------------------------------------------
// ESC PWM
// ---------------------------------------------------------------------------
#define ESC_PWM_HZ          50
#define ESC_PWM_RESOLUTION  16
#define ESC_MIN_US          1000
#define ESC_MAX_US          2000

// ---------------------------------------------------------------------------
// Timing / safety
// ---------------------------------------------------------------------------
#define ESC_ARM_TIME_MS         3000   // hold min pulse before accepting START
#define CONTROL_TIMEOUT_MS      1500   // failsafe if no heartbeat
#define HEARTBEAT_EXPECTED_MS    500   // browser target interval
#define START_RAMP_PCT_PER_S      35   // controlled ramp rate
#define COOLANT_PRIME_MS        2000   // pump run time before TEC enable
#define COOLING_MIN_MOTOR1_PCT    20   // min Motor 1 applied % for TEC

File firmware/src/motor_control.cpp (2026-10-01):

#include "motor_control.h"

namespace MotorControl {

// Stable logical channel IDs are retained for Arduino-ESP32 2.x compatibility.
// Arduino-ESP32 3.x assigns the physical LEDC channel automatically.
static const uint8_t CH_ESC1 = 0;
static const uint8_t CH_ESC2 = 1;

static uint8_t s_m1Target = 0;
static uint8_t s_m2Target = 0;
static uint8_t s_m1Applied = 0;
static uint8_t s_m2Applied = 0;
static bool s_armed = false;
static bool s_running = false;
static bool s_failsafe = false;
static bool s_pwmReady = false;
static uint32_t s_bootMs = 0;
static uint32_t s_lastControlMs = 0;
static uint32_t s_lastRampMs = 0;

static uint32_t pulseToDuty(uint16_t us) {
  // 50 Hz => 20,000 us period. Use the configured LEDC resolution.
  const uint32_t dutyMax = (1UL << ESC_PWM_RESOLUTION) - 1UL;
  return ((uint32_t)us * dutyMax) / 20000UL;
}

static void writeEscPulse(uint8_t pin, uint8_t channel, uint16_t us) {
  us = constrain(us, (uint16_t)ESC_MIN_US, (uint16_t)ESC_MAX_US);
  const uint32_t duty = pulseToDuty(us);

#if defined(ESP_ARDUINO_VERSION_MAJOR) && (ESP_ARDUINO_VERSION_MAJOR >= 3)
  // Arduino-ESP32 3.x LEDC writes are pin-based.
  (void)channel;
  ledcWrite(pin, duty);
#else
  // Arduino-ESP32 2.x LEDC writes are channel-based.
  (void)pin;
  ledcWrite(channel, duty);
#endif
}

static uint16_t percentToPulse(uint8_t pct) {
  pct = constrain(pct, (uint8_t)0, (uint8_t)100);
  return ESC_MIN_US + ((uint32_t)pct * (ESC_MAX_US - ESC_MIN_US)) / 100UL;
}

static void applyOutputs() {
  if (!s_pwmReady) return;
  writeEscPulse(ESC1_PIN, CH_ESC1, percentToPulse(s_m1Applied));
  writeEscPulse(ESC2_PIN, CH_ESC2, percentToPulse(s_m2Applied));
}



void begin() {
  s_bootMs = millis();
  s_lastRampMs = s_bootMs;
  s_lastControlMs = s_bootMs;
  s_armed = false;
  s_running = false;
  s_failsafe = false;
  s_pwmReady = false;
  s_m1Target = s_m2Target = 0;
  s_m1Applied = s_m2Applied = 0;

#if defined(ESP_ARDUINO_VERSION_MAJOR) && (ESP_ARDUINO_VERSION_MAJOR >= 3)
  const bool esc1Ok = ledcAttach(ESC1_PIN, ESC_PWM_HZ, ESC_PWM_RESOLUTION);
  const bool esc2Ok = ledcAttach(ESC2_PIN, ESC_PWM_HZ, ESC_PWM_RESOLUTION);
  s_pwmReady = esc1Ok && esc2Ok;
#else
  ledcSetup(CH_ESC1, ESC_PWM_HZ, ESC_PWM_RESOLUTION);
  ledcSetup(CH_ESC2, ESC_PWM_HZ, ESC_PWM_RESOLUTION);
  ledcAttachPin(ESC1_PIN, CH_ESC1);
  ledcAttachPin(ESC2_PIN, CH_ESC2);
  s_pwmReady = true;
#endif

  if (!s_pwmReady) {
    Serial.println("ERROR: ESC PWM initialization failed; motors locked off.");
    return;
  }

  writeEscPulse(ESC1_PIN, CH_ESC1, ESC_MIN_US);
  writeEscPulse(ESC2_PIN, CH_ESC2, ESC_MIN_US);
  Serial.printf("ESC PWM ready: %u Hz, %u-bit, outputs held at %u us.\n",
                ESC_PWM_HZ, ESC_PWM_RESOLUTION, ESC_MIN_US);
}

void update() {
  if (!s_pwmReady) return;

  if (!s_armed && (millis() - s_bootMs) >= ESC_ARM_TIME_MS) {
    s_armed = true;
    Serial.println("ESC arming complete.");
  }

  if (s_running && !hasRecentControl()) {
    Serial.println("FAILSAFE: control heartbeat timeout");
    triggerFailsafe();
  }

  if (!s_armed || !s_running) {
    if (s_m1Applied || s_m2Applied) {
      s_m1Applied = s_m2Applied = 0;
      applyOutputs();
    }
    return;
  }

  const uint32_t now = millis();
  const uint32_t dt = now - s_lastRampMs;
  if (!dt) return;
  s_lastRampMs = now;

  const uint8_t step = max<uint8_t>(1, (uint8_t)((START_RAMP_PCT_PER_S * dt) / 1000UL));

  if (s_m1Applied < s_m1Target)
    s_m1Applied = min<uint8_t>(s_m1Target, (uint8_t)(s_m1Applied + step));
  else if (s_m1Applied > s_m1Target)
    s_m1Applied = (s_m1Applied > step) ? (uint8_t)(s_m1Applied - step) : 0;

  if (s_m2Applied < s_m2Target)
    s_m2Applied = min<uint8_t>(s_m2Target, (uint8_t)(s_m2Applied + step));
  else if (s_m2Applied > s_m2Target)
    s_m2Applied = (s_m2Applied > step) ? (uint8_t)(s_m2Applied - step) : 0;

  applyOutputs();
}

bool isArmed() { return s_armed && s_pwmReady; }
bool isRunning() { return s_running; }
bool isFailsafe() { return s_failsafe; }

uint8_t motor1Target() { return s_m1Target; }
uint8_t motor2Target() { return s_m2Target; }
uint8_t motor1Applied() { return s_m1Applied; }
uint8_t motor2Applied() { return s_m2Applied; }

void setTargets(uint8_t m1, uint8_t m2) {
  s_m1Target = constrain(m1, (uint8_t)0, (uint8_t)100);
  s_m2Target = constrain(m2, (uint8_t)0, (uint8_t)100);
  touchControl();
}

void start() {
  if (!isArmed()) return;
  s_failsafe = false;
  s_running = true;
  s_lastRampMs = millis();
  touchControl();
}

void stop() {
  s_running = false;
  s_m1Target = s_m2Target = 0;
  s_m1Applied = s_m2Applied = 0;
  applyOutputs();
  touchControl();
}

void triggerFailsafe() {
  s_failsafe = true;
  s_running = false;
  s_m1Target = s_m2Target = 0;
  s_m1Applied = s_m2Applied = 0;
  applyOutputs();
}

void touchControl() {
  s_lastControlMs = millis();
}

bool hasRecentControl() {
  return (millis() - s_lastControlMs) <= CONTROL_TIMEOUT_MS;
}

}  // namespace MotorControl

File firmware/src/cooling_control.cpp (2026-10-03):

#include "cooling_control.h"

namespace CoolingControl {

static uint8_t s_level = 0;
static bool s_pumpOn = false;
static bool s_tecOn = false;
static uint32_t s_primeStartMs = 0;

void begin() {
  s_level = 0;
  s_pumpOn = false;
  s_tecOn = false;
  s_primeStartMs = 0;

#if PUMP_PIN >= 0
  pinMode(PUMP_PIN, OUTPUT);
  digitalWrite(PUMP_PIN, LOW);
#endif
#if TEC_PIN >= 0
  pinMode(TEC_PIN, OUTPUT);
  digitalWrite(TEC_PIN, LOW);
#endif
}

static void setPump(bool on) {
#if PUMP_PIN >= 0
  digitalWrite(PUMP_PIN, on ? HIGH : LOW);
#endif
  s_pumpOn = on;
}

static void setTec(bool on) {
#if TEC_PIN >= 0
  digitalWrite(TEC_PIN, on ? HIGH : LOW);
#endif
  s_tecOn = on;
}

void forceOff() {
  s_level = 0;
  setTec(false);
  setPump(false);
  s_primeStartMs = 0;
}

void setLevel(uint8_t pct) {
  s_level = constrain(pct, (uint8_t)0, (uint8_t)100);
  if (s_level == 0) {
    setTec(false);
    setPump(false);
    s_primeStartMs = 0;
  }
}

void setRequested(bool on) {
  setLevel(on ? 100 : 0);
}

void update(bool systemRunning, uint8_t motor1AppliedPct) {
  // Safety: no cooling unless requested, system running, and Motor 1 airflow OK.
  // No flow/temperature sensors on this prototype — interlocks are software only.
  if (s_level == 0 || !systemRunning || motor1AppliedPct < COOLING_MIN_MOTOR1_PCT) {
    if (s_tecOn) setTec(false);
    if (s_pumpOn) setPump(false);
    s_primeStartMs = 0;
    return;
  }

  if (!s_pumpOn) {
    setPump(true);
    s_primeStartMs = millis();
    return;
  }

  // TEC is binary on this hardware (MOSFET driver). Level > 0 only gates enable.
  if (!s_tecOn && (millis() - s_primeStartMs) >= COOLANT_PRIME_MS) {
    setTec(true);
  }
}

uint8_t level() { return s_level; }
bool isRequested() { return s_level > 0; }
bool isPumpOn() { return s_pumpOn; }
bool isTecOn() { return s_tecOn; }
bool isPriming() { return s_pumpOn && !s_tecOn && s_level > 0; }

}  // namespace CoolingControl

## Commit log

2026-10-01 feat: modular ESP32-C3 SoftAP firmware and project documentation
    Working AirNode Duo controller:
    - SoftAP AirNode-Duo / airnode123 at 192.168.4.1
    - Captive portal DNS + detection URL redirects
    - Dual ESC PWM (GPIO 4/5), 3s arm, controlled ramp
    - Master + independent motor sliders, START/STOP
    - Heartbeat failsafe 1.5s, no auto-restart
    - Cooling: pump prime then TEC, Motor 1 airflow interlock
    - Modular src: wifi, web, motor, cooling, UI, config
    [config.h, cooling_control.cpp, main.cpp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]
2026-10-01 docs: update thermoelectric cooling concept diagram
    Clearer dual-motor layout, coolant loop, Peltier hot/cold sides,
    firmware cooling sequence, power and ESP32 control notes.
2026-10-01 docs: add generated thermoelectric cooling concept illustration
    PNG/JPG concept art for hardware/concept alongside the SVG schematic.
2026-10-01 fix: update ESC PWM for Arduino ESP32 3.x
    [motor_control.cpp]
2026-10-01 fix: correct PWM helper declaration order
    [motor_control.cpp]
2026-10-01 fix: use ESP32-C3 compatible 14-bit ESC PWM
    [config.h]
2026-10-01 fix: retain compatibility channel identifiers
    [motor_control.cpp]
2026-10-01 docs: document PWM compatibility and verification status
2026-10-03 fix: captive portal responses, cooling level API, JSON control
    - Captive detection: Android redirect, Apple/portal HTML serve, no-cache
    - Cooling 0–100% request level (TEC still binary after pump prime)
    - API accepts form-urlencoded and JSON bodies for control/master/cooling
    - Status JSON includes cooling_target and wifi_clients
    - UI cooling slider + clearer interlock hints
    [cooling_control.cpp, web_server.cpp]
2026-10-03 fix: reliable SoftAP captive portal open behavior
    - Android generate_204/gen_204: HTTP 302 to http://192.168.4.1/
    - Apple/Windows probes: serve control UI or meta-refresh landing page
    - onNotFound GET: serve portal HTML (avoids ignored 302 / blank sheet)
    - Extra probe paths (mobile/status.php, kindle stub, check_network_status)
    - SoftAP startup hardened: clean mode switch, fixed AP IP, then DNS *
    [web_server.cpp]
2026-10-07 docs: select 9350-class CW propeller as primary
    Aligns with ~251 mm free fan-guard frames (~236 mm prop disc).
    Current and temperature still require physical measurement with guards.
2026-10-07 hardware: add printed motor frames (61 mm / 71 mm) and docs
    - b-frame-61mm.stl: Motor 2 air-only cage (253.47^2 x 61 mm)
    - b-frame-71mm-cooled.stl: Motor 1 cage with coil space (253.47^2 x 71 mm)
    - t-frame.stl, t-frame-2.stl: top grilles (253.47^2 x 4.54 mm)
    - frames/README: assembly, print settings, 9450 fit, motor inside layout
    - Document 9450 carbon prop as selected primary
    [b-frame-61mm.stl, b-frame-71mm-cooled.stl, t-frame-2.stl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]
2026-10-07 hardware: add center enclosure STLs (130x110x50 body + lid)
    - case-body.stl: 130 x 110 x 50 mm low-profile shell for net/tent
    - cap.stl: 130 x 110 x 15 mm lid
    - Docs: TEC1-12706, 40x40 block, RF-370 pump, flat stack, side exhaust
    [cap.stl, case-body.stl]
2026-10-07 hardware: make center enclosure 3D-printable
    - Open top of case-body for lid access and clean FDM slicing
    - Cleaned mesh normals; print orientation and PETG settings documented
    - Tube-hole and side-exhaust notes for RF-370 / TEC fan
    [cap.stl, case-body.stl]
